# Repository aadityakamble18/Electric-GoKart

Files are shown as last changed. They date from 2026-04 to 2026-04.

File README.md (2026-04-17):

# Electric Go-Kart: Custom Traction Control & BMS on a PVC Chassis





**Hi there! We are Aaditya Amresh Kamble and Yash Kumar.** We are final-year Materials Engineering students at the **Indian Institute of Technology Jodhpur**, working under the guidance of **Dr. Srijan Sengupta**. 

This repository contains the complete source code, MATLAB simulations, and hardware schematics for our capstone project: a fully functional, low-cost electric go-kart built from scratch. We wanted to step out of our materials engineering comfort zone and tackle a complex, multi-domain problem combining mechanical design, embedded C++ programming, and control theory. 

The result? An EV platform that actively manages its own wheel slip and battery safety—all running on a $4 microcontroller!

---

## Key Features

1. **PVC Ladder-Frame Chassis:** We validated the use of solvent-welded Schedule-40 PVC for a low-cost, structurally sound EV prototype frame (with steel inserts at high-stress nodes).
2. **Embedded Traction Control System (TCS):** Because we used dual rear BLDC hub motors without a mechanical differential, we built a proportional feedback TCS in software. It catches and corrects wheel slip in under **240 ms**, preventing spin-outs and reducing current spikes by over 57%.
3. **Custom VRLA Battery Management System (BMS):** A rigid safety watchdog for our 36V Lead-Acid pack. It enforces strict cutoffs for undervoltage (33V), overcurrent (45A), and overtemperature (55°C) to prevent irreversible plate sulfation and thermal runaway.
4. **MATLAB Digital Twin:** A complete mathematical model of the kart's motor dynamics and battery degradation (incorporating Peukert's Law) with custom GUI dashboards to safely tune control gains before track testing.

---

## Repository Structure

```text
📦 Electric-GoKart
 ┣ 📂 Arduino_Code
 ┃ ┣ 📜 Main_Kart_Logic.ino       # Core code containing TCS and BMS loops
 ┃ ┣ 📜 Sensors_Config.h          # INA226 and DS18B20 setup
 ┃ ┗ 📜 StateMachine.cpp          # Precharge and fault-handling logic
 ┣ 📂 MATLAB_Simulations
 ┃ ┣ 📜 EV_Dynamics_Model.m       # Euler integration script for motor physics
 ┃ ┣ 📜 TCS_DigitalTwin.mlapp     # Interactive GUI for Traction Control
 ┃ ┗ 📜 BMS_Visualizer.mlapp      # Interactive GUI for Battery Management
 ┣ 📂 Hardware_Schematics
 ┃ ┣ 📜 Electrical_Architecture.pdf
 ┃ ┣ 📜 PVC_Frame_CAD.SLDPRT
 ┃ ┗ 📜 Steering_Ackermann_2D.pdf
 ┣ 📜 Research_Paper.pdf          # Full IEEE-formatted project paper
 ┗ 📜 README.md
```
## Hardware & Components Overview

* **Microcontroller:** Arduino Nano (ATmega328)
* **Motors:** 2x 36V 350W Brushless DC (BLDC) Hub Motors with Hall Sensors
* **Controllers:** 2x standard 36V/50A E-bike motor controllers (modified via RC low-pass filters to accept PWM from the Arduino)
* **Battery:** 4x 12V 7.2Ah VRLA batteries wired in series (36V nominal)
* **Sensors:** INA226 (I2C Current/Voltage Monitor), DS18B20 (1-Wire Temperature Probes)
* **Safety Hardware:** 200A main contactor, 47Ω/25W precharge resistor, 100A ANL fuse, emergency kill-switch.

---

## How to Run the Simulations

We highly recommend playing with the MATLAB simulations before touching the Arduino code. It helps to understand the physics of what the kart is actually doing.

1. Clone this repository: `git clone https://github.com/aadityakamble18/Electric-GoKart.git`
2. Open MATLAB (R2021a or newer recommended).
3. Navigate to the `MATLAB_Simulations` folder.
4. Run `TCS_DigitalTwin.mlapp` to launch the Traction Control dashboard.
5. Use the sliders to apply throttle, and hit the **"Induce Slip"** button to watch the algorithm catch and correct the wheel speed difference in real-time!

---

## Uploading to the Kart

1. Open the `Arduino_Code` folder using the Arduino IDE.
2. Ensure you have the required libraries installed via the Library Manager:
   * `Wire.h` (Built-in)
   * `DallasTemperature` (For DS18B20)
   * `OneWire`
   * `INA226_WE` (Or your preferred INA226 library)
3. Connect your Arduino Nano, select the correct COM port, and hit Upload.
4. **Safety Warning:** *Always* test the logic with the drive wheels lifted off the ground first!

---

## Real-World Performance

We extensively field-tested this kart. Our data logged an acceleration of 0-15 km/h in ~4 seconds (with a 75kg driver). When we simulated an ice patch by lubricating one rear tire, the Arduino detected the free-spinning wheel and clamped the PWM output down, maintaining straight-line stability just as our MATLAB model predicted. Over 45 minutes of hard track testing, our BMS threw zero nuisance trips.

---

## Read Our Paper

For a deep dive into the math, physics, and control algorithms, please read our full IEEE-formatted research paper included in this repository: `Research_Paper.pdf`.

---

## Acknowledgments

A massive thank you to our guide, **Dr. Srijan Sengupta**, for his patience, advice on dealing with ground-loop issues, and for encouraging us to push the boundaries of what materials engineering students can build.

*Built with sweat, late nights, and a lot of PVC primer at IIT Jodhpur.* 🇮🇳

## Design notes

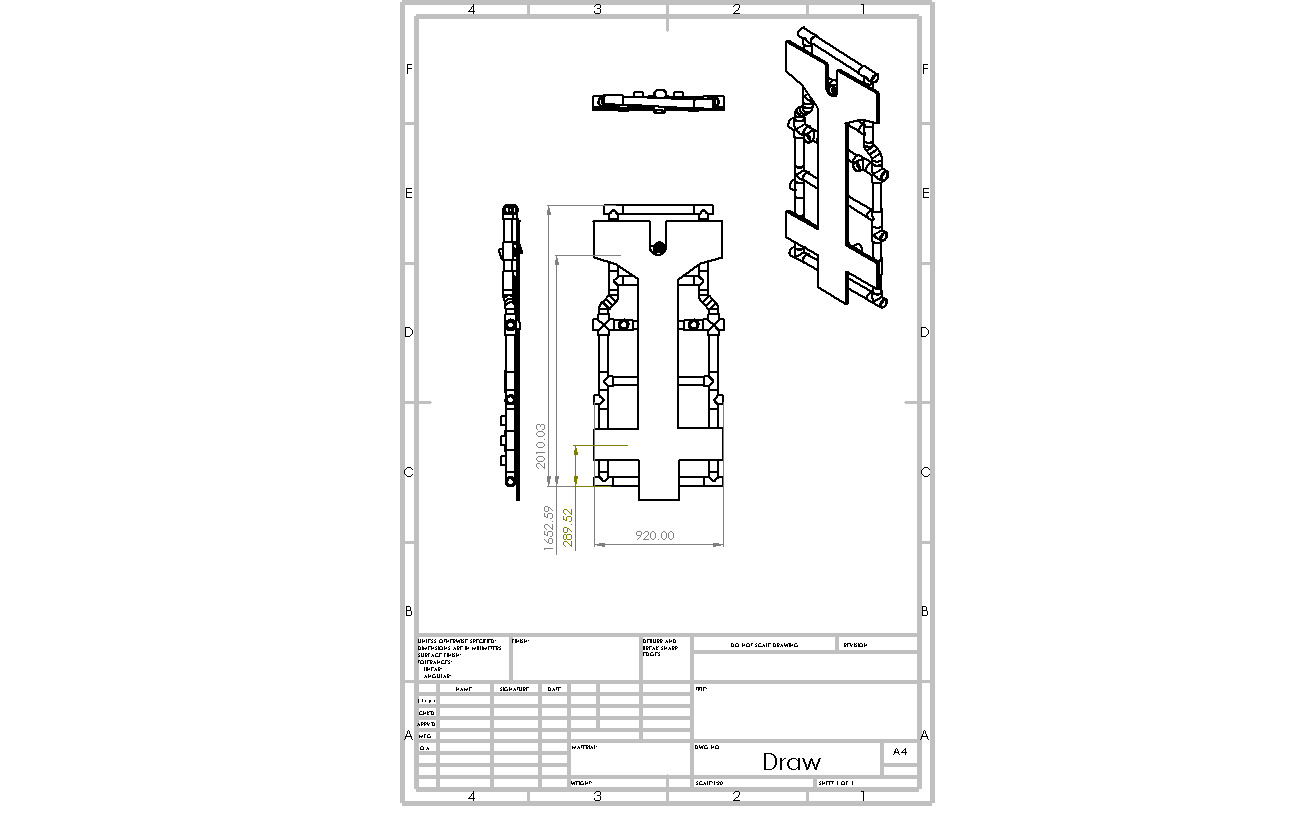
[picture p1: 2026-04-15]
Design/Draw.JPG

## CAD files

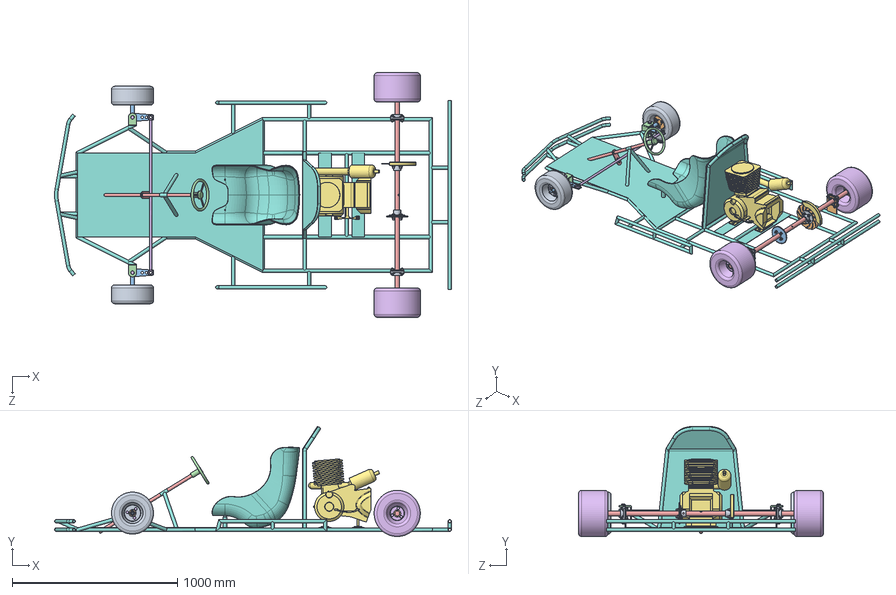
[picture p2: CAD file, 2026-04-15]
Design/V1/Assem1 for road.SLDASM
2400.5 x 665.3 x 1479.6 mm
fornt wheel x 2
wheel hub x 4
Spindle x 2
C Clamp x 2
single row radial ball bearing_is x 6
hexagon fit bolt_is x 22
hexagon nut style 1_is x 2
chacis
bearing bracket x 2
housing x 2
hex flange bolt_is x 8
hexagon nut_is x 28
rear axel rod
rear wheel - x 2
engine
Seat1
Disc hub - x 2
disk plate
sprocket151
steering wheel
ro1
T rod
break shoooooooooooooooooooooooooooo

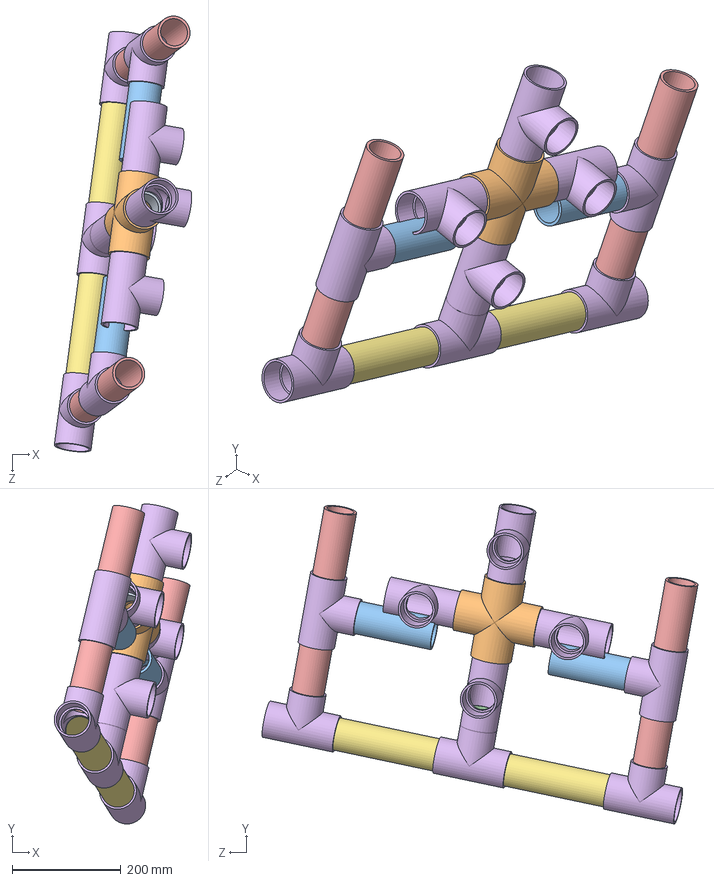
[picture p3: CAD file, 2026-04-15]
Design/Assembly.SLDASM
252.8 x 588.7 x 801.9 mm
Pipe_26 x 2
2in_Tee x 9
Pipe_16 x 4
Pipe_7
Pipe_18 x 2
2in_PCV_cross
Pipe_5 x 4

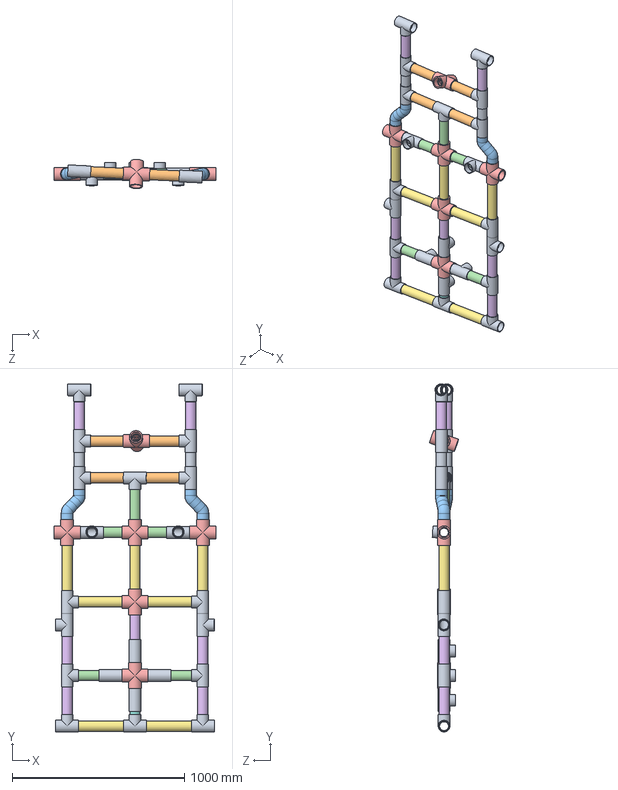
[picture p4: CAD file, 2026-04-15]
Design/Assem1.SLDASM
939.1 x 2017.6 x 169.0 mm
2in_Tee x 22
Pipe_7
Pipe_26 x 7
Pipe_16 x 7
2in_PCV_cross x 6
Pipe_18 x 5
2in_45deg_Elbow x 4
Pipe_21 x 4
Pipe_8 x 2

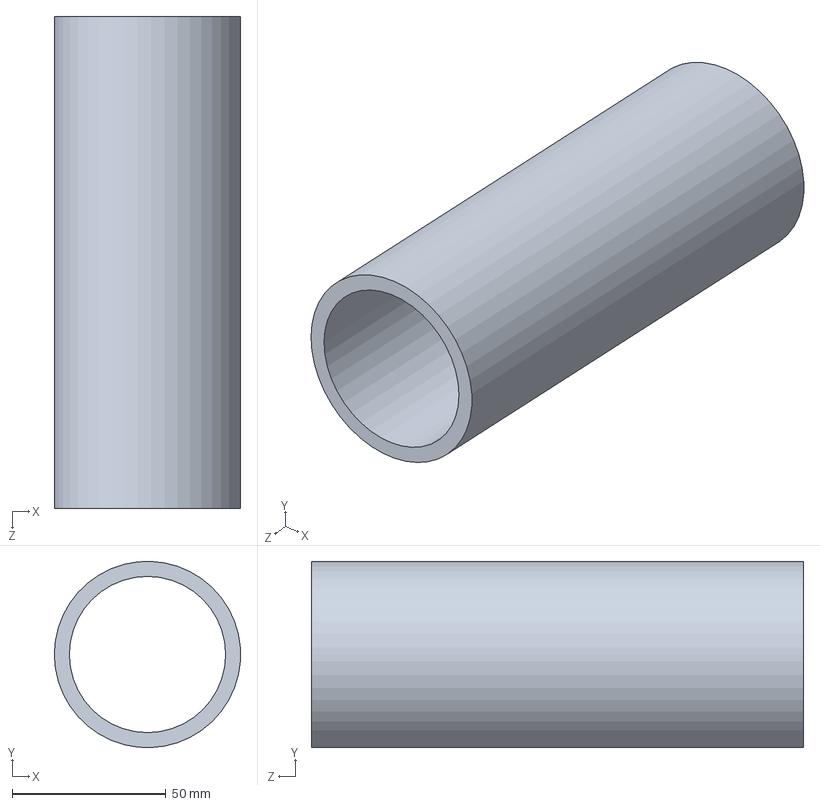
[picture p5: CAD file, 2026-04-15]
Design/Pipe_16.SLDPRT
60.6 x 60.6 x 160.0 mm

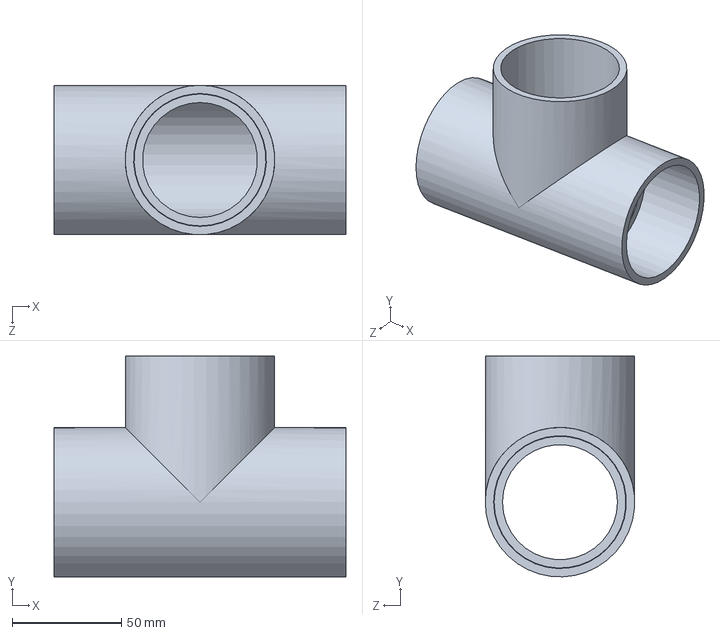
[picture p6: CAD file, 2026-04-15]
Design/2in_Tee.sldprt
133.4 x 100.8 x 68.3 mm

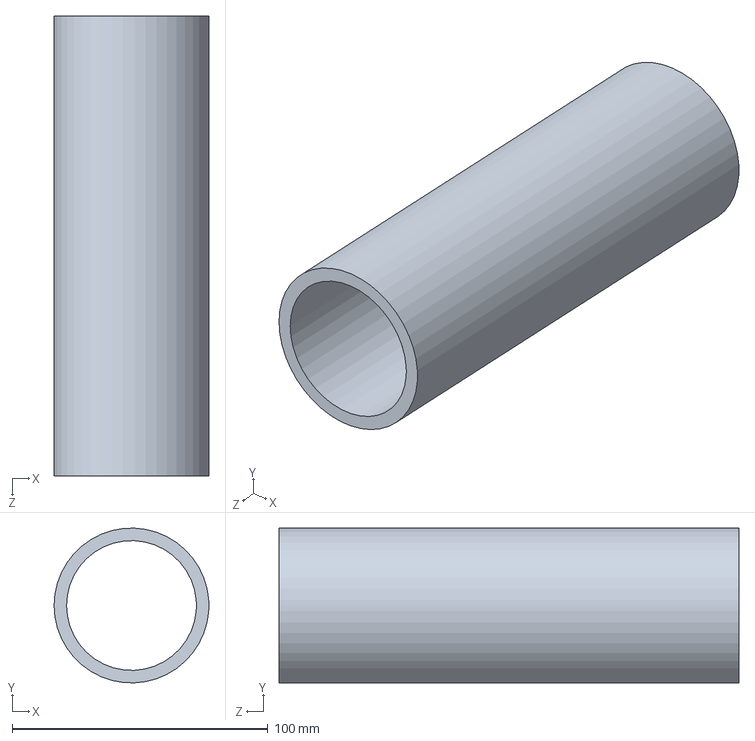
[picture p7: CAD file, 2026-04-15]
Design/Pipe_18.SLDPRT
60.6 x 60.6 x 180.0 mm

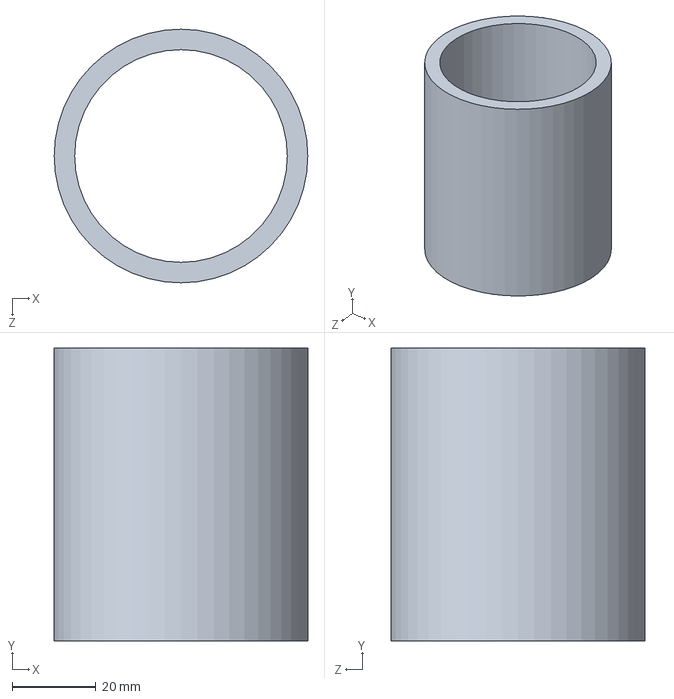
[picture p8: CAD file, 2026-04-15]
Design/Pipe_7_2.SLDPRT
60.6 x 70.0 x 60.6 mm

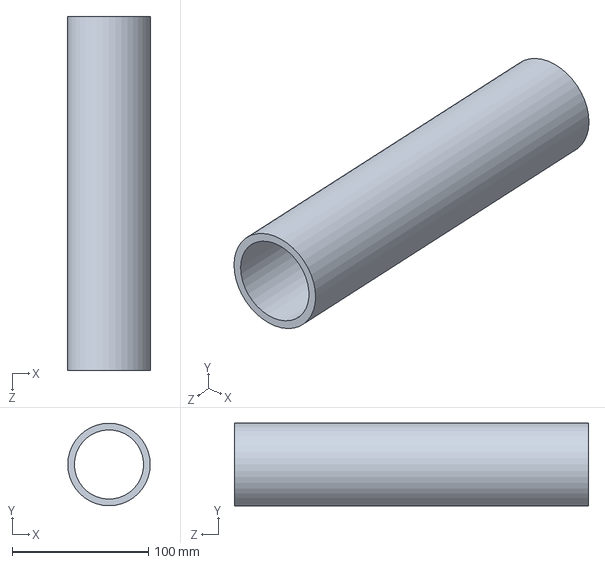
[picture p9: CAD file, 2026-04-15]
Design/Pipe_26.SLDPRT
60.6 x 60.6 x 260.0 mm

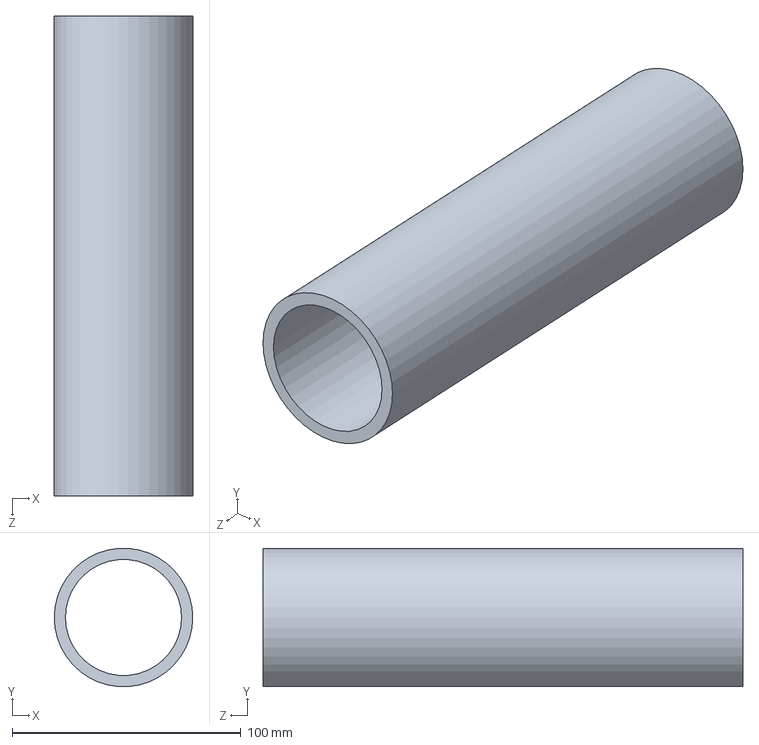
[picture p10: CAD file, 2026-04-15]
Design/Pipe_21.SLDPRT
60.6 x 60.4 x 210.0 mm

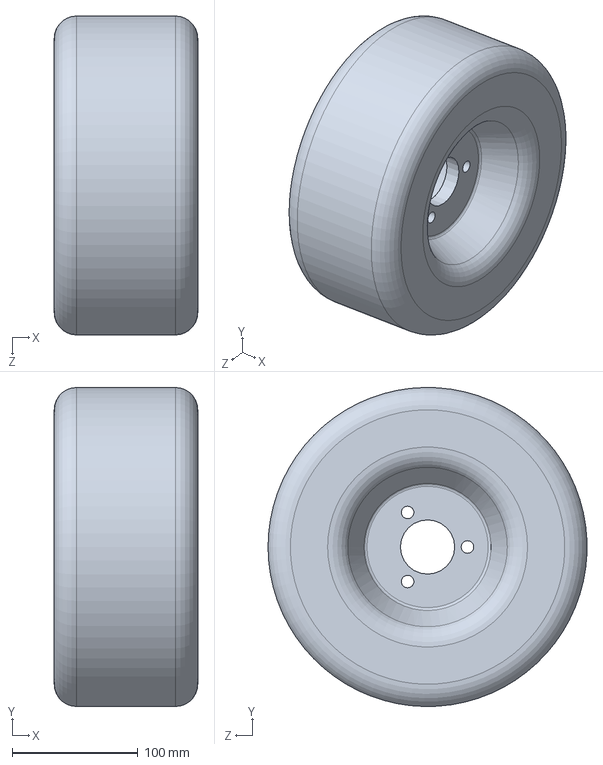
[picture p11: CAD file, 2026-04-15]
Design/fornt wheel.SLDPRT
114.3 x 253.9 x 253.9 mm

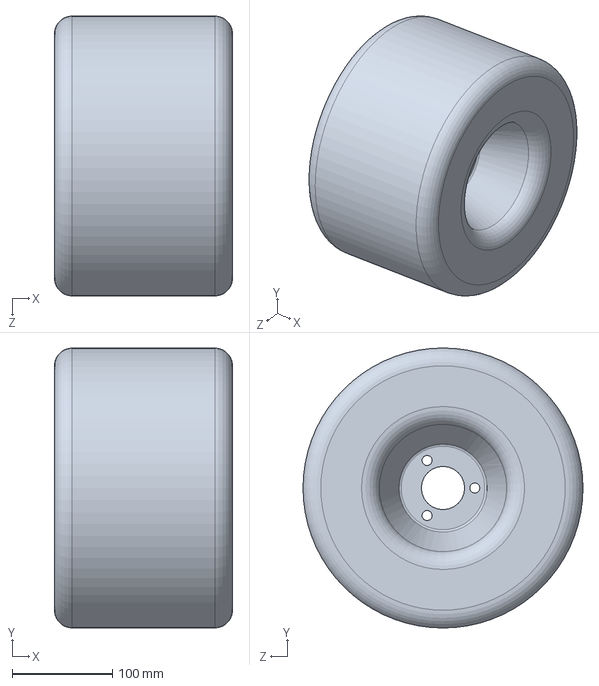
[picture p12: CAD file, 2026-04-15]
Design/rear wheel -.SLDPRT
177.8 x 279.4 x 279.4 mm

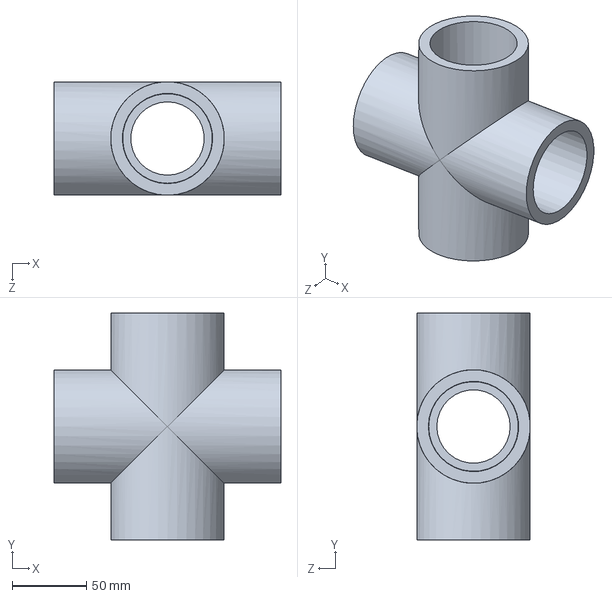
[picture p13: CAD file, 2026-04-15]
Design/2in_PCV_cross.SLDPRT
152.4 x 152.4 x 76.2 mm

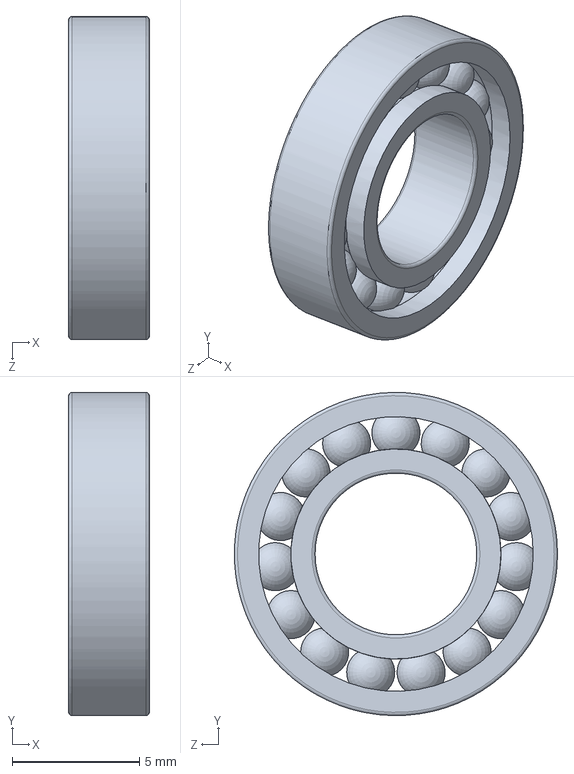
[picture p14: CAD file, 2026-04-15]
Design/bearing.SLDPRT
3.17 x 12.7 x 12.7 mm

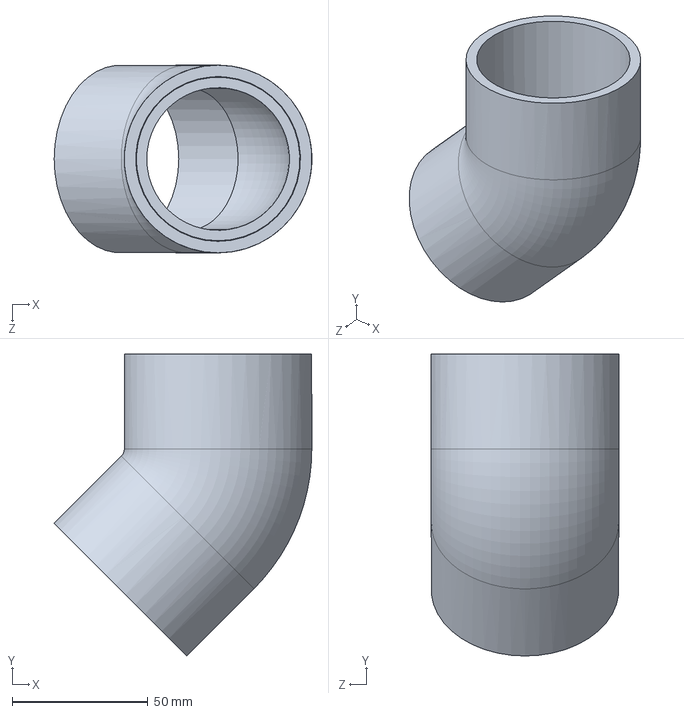
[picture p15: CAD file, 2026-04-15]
Design/2in_45deg_Elbow.sldprt
94.8 x 111.1 x 69.1 mm

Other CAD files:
Design/Pipe_8.SLDPRT
Design/Pipe_5.SLDPRT
Design/Pipe_46.SLDPRT
Design/Draw.SLDDRW
Design/Pipe_50.SLDPRT

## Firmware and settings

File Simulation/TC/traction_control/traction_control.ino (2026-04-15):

/******************************************************
  Traction Control Arduino Sketch
  - Hall sensors on D2, D3 (interrupt pins)
  - Throttle analog on A0
  - Brake on D7 (active LOW)
  - Kill switch on D8 (active LOW)
  - PWM -> controllers on D5, D6 (use RC filters)
  - Contactor MOSFET gate on D10
  - TC enable on D11 (HIGH=ON)
  - Mode switch on D12 (HIGH=Manual, LOW=Auto)
  - Serial debug at 115200 baud
  - Author: ChatGPT (adapted for Aaditya's EV)
******************************************************/

// -------------------- CONFIG -------------------------
const int PIN_HALL1      = 2;    // INT0
const int PIN_HALL2      = 3;    // INT1
const int PIN_THROTTLE   = A0;   // analog throttle (0..1023)
const int PIN_PWM1       = 5;    // PWM -> controller 1
const int PIN_PWM2       = 6;    // PWM -> controller 2
const int PIN_BRAKE      = 7;    // brake switch (active LOW)
const int PIN_KILL       = 8;    // kill switch (active LOW)
const int PIN_CONTACTOR  = 10;   // contactor MOSFET gate (HIGH = coil energized)
const int PIN_TC_ENABLE  = 11;   // Traction Control ON/OFF (HIGH = ON)
const int PIN_MODE       = 12;   // Throttle Mode (HIGH = Manual, LOW = Auto)
const int PIN_LED        = 13;   // on-board LED as heartbeat / status

// Optional sensor pins (not used by default)
const int PIN_ANA_CURRENT = A1;  // optional ACS758 analog current sensor (if used)
// #define USE_INA226 true    // if using INA226 - requires Wire and INA226 library setup
// #define USE_DS18B20 true   // if using DS18B20 - requires OneWire & DallasTemperature libs

// Hardware / physical constants (tuning)
const float HALLS_PER_REV = 3.0;    // number of hall pulses per motor mechanical revolution (change to your motor)
const unsigned long RPM_WINDOW_MS = 200; // compute RPM every 200 ms
const int PWM_MAX = 255;            // 8-bit PWM range

// Traction control tuning params
const float SLIP_THRESHOLD = 0.15;  // 15% above reference considered slip
const float MAX_REDUCTION = 0.6;    // reduce throttle by up to 60% (i.e. to 40%)
const unsigned long SLIP_DEBOUNCE_MS = 120;   // slip must persist this long to be considered real
const unsigned long RECOVER_MS = 250;         // time to confirm recovery
const float PWM_RAMP_STEP = 0.02;  // step per control cycle (0..1) for ramping outputs

// Safety limits
const float PACK_VOLTAGE_NOMINAL = 36.0; // for reference (not measured unless sensor present)
const int PWM_MIN_SAFE = 0;

// -------------------- GLOBALS ------------------------
volatile unsigned long hallCount1 = 0;  // incremented in ISR
volatile unsigned long hallCount2 = 0;

unsigned long lastRPMcheck = 0;
float rpm1 = 0.0, rpm2 = 0.0;

unsigned long lastHallReadTime = 0;

// TC state
bool slipActive1 = false;
bool slipActive2 = false;
unsigned long slipStart1 = 0, slipStart2 = 0;
unsigned long recoverStart1 = 0, recoverStart2 = 0;

// PWM outputs in fractional (0..1)
float pwmOut1 = 0.0;
float pwmOut2 = 0.0;

// timing
unsigned long lastLoopMicros = 0;
unsigned long loopIntervalMicros = 20000; // target loop 50 Hz => 20 ms

// For auto mode simple profile
unsigned long startMillis = 0;
float autoTarget = 0.8; // default auto target throttle

// -------------------- SETUP --------------------------
void setup() {
  Serial.begin(115200);
  pinMode(PIN_HALL1, INPUT_PULLUP);
  pinMode(PIN_HALL2, INPUT_PULLUP);
  attachInterrupt(digitalPinToInterrupt(PIN_HALL1), hall1_isr, RISING);
  attachInterrupt(digitalPinToInterrupt(PIN_HALL2), hall2_isr, RISING);

  pinMode(PIN_BRAKE, INPUT_PULLUP);   // active LOW
  pinMode(PIN_KILL, INPUT_PULLUP);    // active LOW
  pinMode(PIN_CONTACTOR, OUTPUT);
  digitalWrite(PIN_CONTACTOR, LOW);   // ensure contactor off at boot
  pinMode(PIN_PWM1, OUTPUT);
  pinMode(PIN_PWM2, OUTPUT);
  analogWrite(PIN_PWM1, 0);
  analogWrite(PIN_PWM2, 0);

  pinMode(PIN_TC_ENABLE, INPUT_PULLUP);  // if switch to ground to enable, invert logic; here HIGH=ON expected
  pinMode(PIN_MODE, INPUT_PULLUP);       // HIGH = Manual, LOW = Auto
  pinMode(PIN_LED, OUTPUT);

  lastRPMcheck = millis();
  startMillis = millis();
  lastLoopMicros = micros();

  Serial.println("Traction Control unit starting...");
  Serial.print("RPM window (ms): "); Serial.println(RPM_WINDOW_MS);
  Serial.print("PWM ramp step: "); Serial.println(PWM_RAMP_STEP);
}

// -------------------- ISRs ----------------------------
void hall1_isr() {
  hallCount1++;
}
void hall2_isr() {
  hallCount2++;
}

// -------------------- MAIN LOOP -----------------------
void loop() {
  // pacing loop to approx 50 Hz
  unsigned long nowMic = micros();
  if (nowMic - lastLoopMicros < loopIntervalMicros) {
    // allow background housekeeping
    delay(0);
    return;
  }
  lastLoopMicros = nowMic;

  // read inputs
  bool killPressed = (digitalRead(PIN_KILL) == LOW);   // active low
  bool brakePressed = (digitalRead(PIN_BRAKE) == LOW);
  bool tcEnabled = (digitalRead(PIN_TC_ENABLE) == HIGH);
  bool manualMode = (digitalRead(PIN_MODE) == HIGH);

  // immediate kill: cut outputs and open contactor
  if (killPressed) {
    doKill();
    return; // remain in loop but outputs are off
  }

  // Manage contactor: simple auto-close on start; user can extend logic to precharge
  if (millis() - startMillis > 200 && digitalRead(PIN_CONTACTOR) == LOW) {
    // energize contactor
    digitalWrite(PIN_CONTACTOR, HIGH);
  }

  // read throttle
  int rawThrottle = analogRead(PIN_THROTTLE); // 0..1023
  float throttle = rawThrottle / 1023.0;
  // apply deadband and linearization if wanted
  if (throttle < 0.02) throttle = 0.0;

  // if auto mode: create simple step profile: ramp to autoTarget after 2s
  if (!manualMode) {
    unsigned long t = millis() - startMillis;
    unsigned long stepTime = 2000;
    if (t >= stepTime) throttle = autoTarget;
    else throttle = ( (float)t / (float)stepTime ) * autoTarget;
  }

  // apply brake: simple approach -> reduce throttle
  float brakeVal = brakePressed ? 1.0 : 0.0;
  float thrReq = throttle * (1.0f - brakeVal);

  // compute RPMs periodically
  unsigned long now = millis();
  if (now - lastRPMcheck >= RPM_WINDOW_MS) {
    noInterrupts();
    unsigned long c1 = hallCount1;
    unsigned long c2 = hallCount2;
    hallCount1 = 0;
    hallCount2 = 0;
    interrupts();
    float windowSec = (now - lastRPMcheck) / 1000.0;
    // pulses -> revs
    float revs1 = (c1 / HALLS_PER_REV);
    float revs2 = (c2 / HALLS_PER_REV);
    rpm1 = (windowSec > 0) ? (revs1 / windowSec * 60.0) : rpm1;
    rpm2 = (windowSec > 0) ? (revs2 / windowSec * 60.0) : rpm2;
    lastRPMcheck = now;
  }

  // reference RPM: average or map from throttle; we use average of both if >0 else throttle->rpm mapping
  float rpmRef;
  if (rpm1 + rpm2 > 50.0) {
    rpmRef = (rpm1 + rpm2) / 2.0;
  } else {
    // approximate mapping throttle->rpmRef, needs tuning for your vehicle
    float noload_rpm = 4500.0;
    rpmRef = thrReq * noload_rpm;
  }

  // Traction control logic
  if (tcEnabled) {
    // motor1 slip
    float slip1 = (rpmRef > 1.0) ? (rpm1 - rpmRef) / rpmRef : 0.0;
    if (slip1 > SLIP_THRESHOLD) {
      if (!slipActive1) {
        if (slipStart1 == 0) slipStart1 = millis();
        if (millis() - slipStart1 >= SLIP_DEBOUNCE_MS) slipActive1 = true;
      }
    } else {
      slipStart1 = 0;
      if (slipActive1) {
        if (slip1 < SLIP_THRESHOLD * 0.3) {
          if (recoverStart1 == 0) recoverStart1 = millis();
          if (millis() - recoverStart1 >= RECOVER_MS) { slipActive1 = false; recoverStart1 = 0; }
        } else {
          recoverStart1 = 0;
        }
      }
    }
    // motor2 slip
    float slip2 = (rpmRef > 1.0) ? (rpm2 - rpmRef) / rpmRef : 0.0;
    if (slip2 > SLIP_THRESHOLD) {
      if (!slipActive2) {
        if (slipStart2 == 0) slipStart2 = millis();
        if (millis() - slipStart2 >= SLIP_DEBOUNCE_MS) slipActive2 = true;
      }
    } else {
      slipStart2 = 0;
      if (slipActive2) {
        if (slip2 < SLIP_THRESHOLD * 0.3) {
          if (recoverStart2 == 0) recoverStart2 = millis();
          if (millis() - recoverStart2 >= RECOVER_MS) { slipActive2 = false; recoverStart2 = 0; }
        } else {
          recoverStart2 = 0;
        }
      }
    }
  } else {
    // if TC disabled, clear all flags
    slipActive1 = slipActive2 = false;
    slipStart1 = slipStart2 = recoverStart1 = recoverStart2 = 0;
  }

  // compute per-motor targets
  float target1 = thrReq;
  float target2 = thrReq;
  if (slipActive1) target1 = thrReq * (1.0 - MAX_REDUCTION);
  if (slipActive2) target2 = thrReq * (1.0 - MAX_REDUCTION);

  // smooth ramping: move pwmOut toward target with step
  pwmOut1 = rampToward(pwmOut1, target1, PWM_RAMP_STEP);
  pwmOut2 = rampToward(pwmOut2, target2, PWM_RAMP_STEP);

  // Convert to PWM values 0..255
  int pwmVal1 = (int)(pwmOut1 * PWM_MAX + 0.5);
  int pwmVal2 = (int)(pwmOut2 * PWM_MAX + 0.5);
  pwmVal1 = constrain(pwmVal1, PWM_MIN_SAFE, PWM_MAX);
  pwmVal2 = constrain(pwmVal2, PWM_MIN_SAFE, PWM_MAX);

  analogWrite(PIN_PWM1, pwmVal1);
  analogWrite(PIN_PWM2, pwmVal2);

  // Heartbeat LED blink
  static unsigned long lastBlink = 0;
  if (millis() - lastBlink > 300) {
    digitalWrite(PIN_LED, !digitalRead(PIN_LED));
    lastBlink = millis();
  }

  // Serial telemetry (periodic)
  static unsigned long lastSerial = 0;
  if (millis() - lastSerial > 250) {
    Serial.print("T=");
    Serial.print(thrReq,3);
    Serial.print(" |rpm1=");
    Serial.print(rpm1,1);
    Serial.print(" rpm2=");
    Serial.print(rpm2,1);
    Serial.print(" |pwm1=");
    Serial.print(pwmVal1);
    Serial.print(" pwm2=");
    Serial.print(pwmVal2);
    Serial.print(" |slip1=");
    Serial.print(slipActive1);
    Serial.print(" slip2=");
    Serial.print(slipActive2);
    Serial.println();
    lastSerial = millis();
  }

  // small safety: if brake is pressed -> force pwm outputs to zero immediately
  if (brakePressed) {
    pwmOut1 = pwmOut2 = 0.0;
    analogWrite(PIN_PWM1, 0);
    analogWrite(PIN_PWM2, 0);
  }
}

// -------------------- helper functions --------------------
float rampToward(float current, float target, float step) {
  if (abs(target - current) <= step) return target;
  if (target > current) return current + step;
  else return current - step;
}

void doKill() {
  // immediate shutdown
  analogWrite(PIN_PWM1, 0);
  analogWrite(PIN_PWM2, 0);
  digitalWrite(PIN_CONTACTOR, LOW); // open contactor
  pwmOut1 = pwmOut2 = 0.0;
  Serial.println("KILL SWITCH PRESSED - SYSTEM OFF");
  // block here until kill is released to prevent accidental restart
  while (digitalRead(PIN_KILL) == LOW) {
    delay(50);
  }
  Serial.println("Kill released - manual restart required.");
}

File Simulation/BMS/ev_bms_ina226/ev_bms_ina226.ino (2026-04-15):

/*
  ev_bms_ina226.ino
  Arduino BMS for 36V VRLA pack using INA226 (I2C) and 3x DS18B20.
  - Pack voltage on A0 (Rtop=80k, Rbot=10k)
  - INA226 on I2C measures shunt (0.001 ohm)
  - DS18B20 1-wire on D2 (4.7k pull-up to 5V)
  - Precharge relay driver on D3 (MOSFET gate)
  - Contactor driver on D4 (MOSFET gate)
  - Buzzer on D5, Green LED D6, Red LED D7
  - Start/Reset button on D8 (INPUT_PULLUP)
*/

#include <Wire.h>
#include <OneWire.h>
#include <DallasTemperature.h>

// ---------------- Configuration ----------------
const uint8_t INA226_ADDR = 0x40; // INA226 I2C address (change if different)
const float R_SHUNT = 0.001f;     // shunt in ohms (1 mΩ)
const float MAX_EXPECTED_CURRENT_A = 150.0f;
const float PREFERRED_CURRENT_LSB = 0.005f; // 5 mA LSB if sufficient

// Voltage divider constants (Rtop=80k, Rbot=10k)
const float ADC_REF = 5.00f;
const int ADC_MAX = 1023;
const float DIVIDER_RATIO = 9.0f; // (Rtop+Rbot)/Rbot = 90k/10k

// Pins
const int PIN_VPACK_ADC = A0;
const int PIN_DS18B20 = 2;
const int PIN_PRECHARGE = 3;
const int PIN_CONTACTOR = 4;
const int PIN_BUZZER = 5;
const int PIN_LED_GREEN = 6;
const int PIN_LED_RED = 7;
const int PIN_BUTTON = 8;

// Protection thresholds
const float PACK_CUTOFF_V = 35.0f;
const float PACK_RECONNECT_V = 36.8f;
const float PACK_RECONNECT_TIME = 10.0f; // seconds
const float OVERCURRENT_THRESHOLD_A = 80.0f;
const float OVERCURRENT_INSTANT_A = 120.0f;
const unsigned long OVERCURRENT_TIME_MS = 250;
const float OVERTEMP_TRIP_C = 55.0f;
const float OVERTEMP_WARN_C = 50.0f;

// Precharge timing
const unsigned long PRECHARGE_MIN_MS = 1200;
const unsigned long PRECHARGE_TIMEOUT_MS = 8000;

// smoothing
const float ALPHA = 0.2f;

// ---------------- INA226 register addresses ----------------
#define INA226_REG_CONFIG     0x00
#define INA226_REG_SHUNTVOLT  0x01
#define INA226_REG_BUSVOLT    0x02
#define INA226_REG_POWER      0x03
#define INA226_REG_CURRENT    0x04
#define INA226_REG_CALIB      0x05

// ---------------- Globals & state ----------------
OneWire oneWire(PIN_DS18B20);
DallasTemperature sensors(&oneWire);
DeviceAddress tempAddresses[8];
int tempCount = 0;

enum State { STATE_OFF, STATE_PRECHARGE, STATE_RUNNING, STATE_FAULT_UNDERVOLT, STATE_FAULT_OVERCURRENT, STATE_FAULT_OVERTEMP, STATE_MANUAL_LOCK};
State state = STATE_OFF;

unsigned long prechargeStart = 0;
unsigned long overcurrentStartMs = 0;
unsigned long lastReconnectStart = 0;
unsigned long lastSerialMs = 0;
unsigned long lastButtonMillis = 0;
bool lastButtonState = HIGH;

float packVoltageFilt = 0.0f;
float currentFilt = 0.0f;

// INA226 calibration values
uint16_t ina226_cal_reg = 0;
float ina_current_lsb = 0.0f; // A per bit

// ---------------- Prototypes ----------------
void ina226WriteRegister(uint8_t reg, uint16_t value);
uint16_t ina226ReadRegister(uint8_t reg);
void ina226Init();
float ina226ReadShuntVoltage_V();
float ina226ReadBusVoltage_V();
float ina226ReadCurrent_A();

float readPackVoltage();
float readMaxTemperature();
void handleButtonPress();
void tripToFault(State f);
const char* stateToString(State s);
void printAddress(DeviceAddress deviceAddress);

// ---------------- Setup ----------------
void setup() {
  Serial.begin(115200);
  delay(50);
  Serial.println(F("EV BMS w/ INA226 starting..."));

  pinMode(PIN_PRECHARGE, OUTPUT);
  pinMode(PIN_CONTACTOR, OUTPUT);
  pinMode(PIN_BUZZER, OUTPUT);
  pinMode(PIN_LED_GREEN, OUTPUT);
  pinMode(PIN_LED_RED, OUTPUT);
  pinMode(PIN_BUTTON, INPUT_PULLUP);

  digitalWrite(PIN_PRECHARGE, LOW);
  digitalWrite(PIN_CONTACTOR, LOW);
  digitalWrite(PIN_BUZZER, LOW);
  digitalWrite(PIN_LED_GREEN, LOW);
  digitalWrite(PIN_LED_RED, LOW);

  sensors.begin();
  tempCount = sensors.getDeviceCount();
  Serial.print(F("DS18B20 count: "));
  Serial.println(tempCount);
  for (int i=0;i<tempCount;i++){
    if (sensors.getAddress(tempAddresses[i], i)) {
      Serial.print(F("Found temp sensor: "));
      printAddress(tempAddresses[i]);
      Serial.println();
    }
  }

  Wire.begin(); // I2C
  ina226Init();

  state = STATE_OFF;
  packVoltageFilt = readPackVoltage();
  currentFilt = ina226ReadCurrent_A();
  lastSerialMs = millis();
}

// ---------------- Loop ----------------
void loop() {
  unsigned long now = millis();

  float vpack = readPackVoltage();
  packVoltageFilt = (1.0f - ALPHA) * packVoltageFilt + ALPHA * vpack;

  float currentA = ina226ReadCurrent_A();
  currentFilt = (1.0f - ALPHA) * currentFilt + ALPHA * currentA;

  float maxTemp = readMaxTemperature();

  bool btn = digitalRead(PIN_BUTTON);
  if (btn == LOW && lastButtonState == HIGH && (now - lastButtonMillis) > 200) {
    lastButtonMillis = now;
    handleButtonPress();
  }
  lastButtonState = btn;

  switch(state) {
    case STATE_OFF:
      digitalWrite(PIN_CONTACTOR, LOW);
      digitalWrite(PIN_PRECHARGE, LOW);
      digitalWrite(PIN_LED_GREEN, LOW);
      digitalWrite(PIN_LED_RED, HIGH);
      if (btn == LOW) {
        Serial.println(F("Start pressed -> PRECHARGE"));
        state = STATE_PRECHARGE;
        digitalWrite(PIN_PRECHARGE, HIGH);
        prechargeStart = now;
        digitalWrite(PIN_BUZZER, HIGH); delay(80); digitalWrite(PIN_BUZZER, LOW);
      }
      break;

    case STATE_PRECHARGE:
      digitalWrite(PIN_LED_RED, HIGH);
      if (now - prechargeStart >= PRECHARGE_MIN_MS) {
        Serial.println(F("Precharge done -> close contactor"));
        digitalWrite(PIN_CONTACTOR, HIGH);
        delay(200);
        digitalWrite(PIN_PRECHARGE, LOW);
        state = STATE_RUNNING;
        digitalWrite(PIN_LED_GREEN, HIGH);
        digitalWrite(PIN_LED_RED, LOW);
        digitalWrite(PIN_BUZZER, HIGH); delay(50); digitalWrite(PIN_BUZZER, LOW);
      } else if (now - prechargeStart >= PRECHARGE_TIMEOUT_MS) {
        Serial.println(F("Precharge timeout, forcing contactor close"));
        digitalWrite(PIN_CONTACTOR, HIGH);
        delay(200);
        digitalWrite(PIN_PRECHARGE, LOW);
        state = STATE_RUNNING;
      }
      break;

    case STATE_RUNNING:
      digitalWrite(PIN_LED_GREEN, HIGH);
      digitalWrite(PIN_LED_RED, LOW);

      if (packVoltageFilt <= PACK_CUTOFF_V) {
        Serial.println(F("UNDERVOLT TRIP"));
        tripToFault(STATE_FAULT_UNDERVOLT);
        break;
      }
      if (maxTemp >= OVERTEMP_TRIP_C) {
        Serial.println(F("OVERTEMP TRIP"));
        tripToFault(STATE_FAULT_OVERTEMP);
        break;
      }
      if (currentFilt >= OVERCURRENT_INSTANT_A) {
        Serial.println(F("INSTANT OVERCURRENT TRIP"));
        tripToFault(STATE_FAULT_OVERCURRENT);
        break;
      } else if (currentFilt >= OVERCURRENT_THRESHOLD_A) {
        if (overcurrentStartMs == 0) overcurrentStartMs = now;
        if ((now - overcurrentStartMs) >= OVERCURRENT_TIME_MS) {
          Serial.println(F("SUSTAINED OVERCURRENT TRIP"));
          tripToFault(STATE_FAULT_OVERCURRENT);
          overcurrentStartMs = 0;
          break;
        }
      } else {
        overcurrentStartMs = 0;
      }
      break;
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

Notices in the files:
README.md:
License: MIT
